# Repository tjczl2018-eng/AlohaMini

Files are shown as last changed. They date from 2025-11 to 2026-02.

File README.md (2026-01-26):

# AlohaMini
 

AlohaMini is a dual-arm mobile robot with a motorized vertical lift — beautifully designed, fully 3D-printable, and affordable.  

Built for embodied AI research and real-world manipulation. Assemble at home in ~60 minutes, customize every part, and train or deploy with LeRobot.

Note:
Use ROS only if you need URDF visualization, RViz inspection, or Gazebo simulation.

## Updates

- [2025-12-18] — URDF and simulation assets are now available for visualization and simulation (`simulation/src/Aloha/`)
- [2025-11-27] STEP (CAD) files are now available (`/hardware/mobile_base/step/`)

### What Makes It Different

- **Motorized vertical lift** — 0–60 cm travel (floor-to-table reach)
- **5-camera perception system** — top, front, back, and dual arm cameras engineered for embodied-AI reproducibility
- **Completely open-source** — hardware and software freely available
- **LeRobot-compatible** — works out of the box
- **Clean, modern design** — built for both function and aesthetics
- **Low-cost & accessible** — engineered so anyone can build a capable robot at home

## 📸 Gallery

<p align="center">
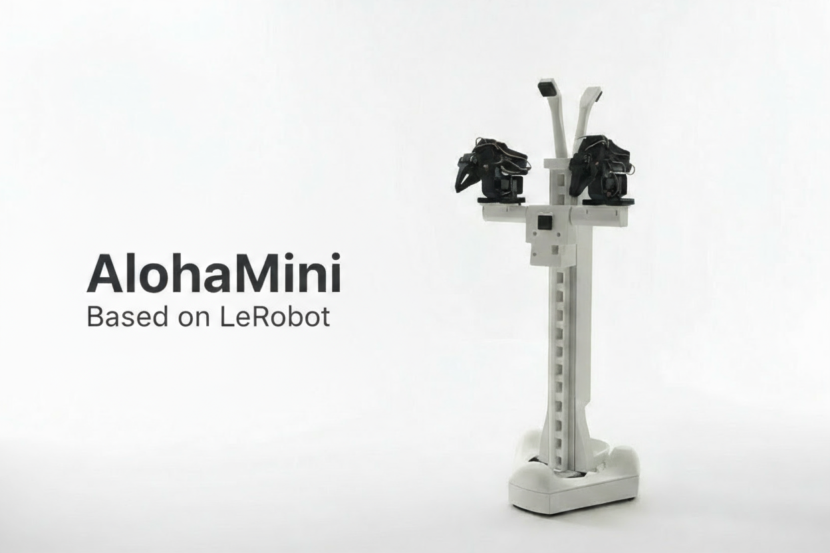
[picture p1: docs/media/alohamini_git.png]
  
</p>

## ⚙️ Bill of Materials (BOM)
### Main Components

| Component | Model / Notes | Qty | Unit Price (USD) |
|---|---|-----|---|
| Servo motors | Feetech STS3215 (12V bus) | 16 | $13.89 |
| Motor control boards | Waveshare Bus Servo Adapter (A) | 2 | $10.55 |
| Compute platform | Raspberry Pi 5 (4/8GB) | 1 | $80 |
| Cameras | 720p USB cameras (2 for arms, 3 for mobile base) | 5 | $20 |
| Mobility system | Omni wheels | 3 | $36.00 |
| Battery | 12V Li-ion pack | 2 | $32.99 |
| Frame | 3D-printed body (ABS / PETG / PLA) | — | ~4kg filament (self-print) |
| **Total** | — | — | **~$600 (self-print)** |

Note: 
- Printable STL files under `/hardware/`
- Compute platform can be replaced with Jetson Nano or similar SBCs if desired.
- URDF files will be released soon

## Quick Start

Start building and running AlohaMini:

1. **Hardware acquisition** — Purchase components and 3D print parts  
   See **[BOM & 3D-Print](docs/BOM.md)**

1. **Assembly** — build the robot in ~60 minutes (SO-ARM pre-assembled)  
   See **[assembly guide](docs/hardware_assembly.md)**

1. **Software setup & teleoperation** — install, connect, and control the robot  
   See **[software guide](software)**

##  Product Line
| Model | Build | Rigidity | Target Users |
|---|---|---|---|
| **AlohaMini** | Fully 3D-printed | Standard | Education, makers, research labs, home builds |
| **AlohaMini Pro** | Hybrid **3D-print + metal** | **3×–5× stiffer** | Algorithm-focused researchers who need plug-and-play, reliable, and stable hardware — without assembly effort |

> Same URDF & control stack across both versions — only structural materials differ.

### AlohaMini Pro Access  
Pro hardware & kits available for advanced users.  
📩 **Contact to request early access.**

## Contact
Email: liyiteng+github@gmail.com  
WeChat: liyiteng  
Videos & tutorials soon on: Bilibili / YouTube / TikTok

## Team
AlohaMini is created by:  
**Li Yiteng** / **Wu Zhiyong**

##  Acknowledgements
Thanks to the open robotics community:  
**ALOHA · LeKiwi · SO-ARM100 · SO-ARM100-Track-Axis · Pi-0.5 · LeRobot · Hugging Face**

## ⭐ Support AlohaMini
If you like this project:
- ⭐ Star the repo  
- 🔔 Follow updates  
- 💬 Join the community

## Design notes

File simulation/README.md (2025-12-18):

# AlohaMini-Simulation

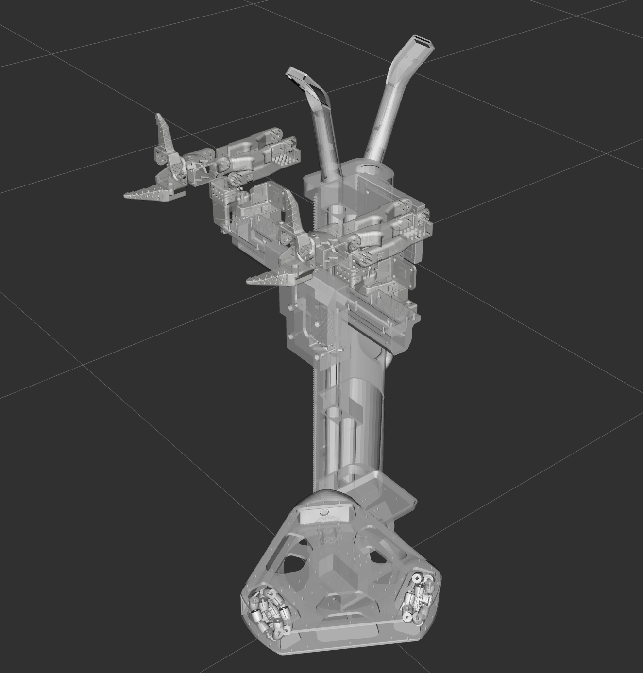
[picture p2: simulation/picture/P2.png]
AlohaMini preview


AlohaMini-Simulation bases on AlohaMini, which link is https://github.com/liyiteng/AlohaMini.

It visualizes the AlohaMini robot using RViz in both ROS 1 and ROS 2, and includes optional Gazebo integration for simulation.

This document provides separate, explicit instructions for ROS 2 and ROS 1: each section contains build (compile) and run (launch) steps targeted at typical Linux (Ubuntu) environments.

## Repository

```bash
git clone https://github.com/lemon198/AlohaMini-Simulation.git
cd AlohaMini-Simulation
```

## ROS 2 — Build & Run (colcon)

These instructions target ROS 2 (colcon-based workspaces). Adjust the distro names (Foxy/Galactic/Humble/Jazzy) as needed.

1) Install prerequisites (example):

```bash
# install colcon and ros dependencies (example for Ubuntu)
sudo apt update
sudo apt install -y python3-colcon-common-extensions python3-rosdep
```

2) Build the workspace:

```bash
colcon build   # run from repository root
```

3) Source the overlay before running:

```bash
source install/setup.bash
```

4) (Optional) Force FastDDS as the RMW implementation:

```bash
export RMW_IMPLEMENTATION=rmw_fastrtps_cpp
```

5) Run RViz2 visualization (example):

```bash
ros2 launch Aloha display.launch.py  # RViz2 visualization
```

Notes for ROS 2:
- Ensure you installed ROS 2 for your target distro and that `source /opt/ros/<distro>/setup.bash` is present in your shell if needed.
- If using mixed ROS1/ROS2 setups, configure the ROS1-ROS2 bridge separately.

## ROS 1 — Build & Run (catkin)

These instructions target ROS 1 (catkin-based workspaces) such as Melodic or Noetic.

1) Create a catkin workspace and place the repository in `src`:

```bash
mkdir -p ~/catkin_ws/src
cd ~/catkin_ws/src
git clone https://github.com/lemon198/AlohaMini-Simulation.git
cd ~/catkin_ws
```

2) Install and resolve dependencies with `rosdep`:

```bash
sudo apt update
sudo apt install -y python3-rosdep
sudo rosdep init   # only if rosdep isn't initialized yet
rosdep update
rosdep install --from-paths src --ignore-src -r -y
```

3) Build with `catkin_make`:

```bash
catkin_make
source devel/setup.bash
```

Or build with `catkin_tools` (`catkin build`):

```bash
sudo apt install -y python3-catkin-tools
cd ~/catkin_ws
catkin build
source devel/setup.bash
```

4) Run ROS 1 launch files:

```bash
roslaunch Aloha display.launch       # RViz visualization
roslaunch Aloha gazebo.launch        # Gazebo visualization
```

Notes for ROS 1:
- These commands are intended for Linux (Ubuntu). For Windows, use WSL or a Linux VM for better ROS1 support.
- If you see missing packages, double-check that package names and dependencies match your ROS distro (Melodic vs Noetic).

## Troubleshooting

- If RViz/RViz2 does not show robot models, ensure `robot_state_publisher` is running and `/tf` topics are being published.
- For mixed ROS1/ROS2 systems, verify your ROS1-ROS2 bridge configuration and topic remapping.
- If launches fail due to missing dependencies, run `rosdep install --from-paths src --ignore-src -r -y` in the workspace root.

## Contributing

Contributions are welcome. Please open issues or PRs against the upstream repository and follow its contribution guidelines.

E-mail address：s-wyw25@bjzgca.edu.cn

## Acknowledgements
Thanks to the open robotics community:

AlohaMini · ALOHA · SO-ARM101 · LeRobot 

## Future

I'll keep exploring VLA algorithms on AlohaMini and will continuously updates. Your stars are what keep this project moving forward.

## License

See the `LICENSE` file in the repository for license details.

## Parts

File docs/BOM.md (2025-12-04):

# Bill of Materials

AlohaMini follows the same architecture and terminology as LeKiwi, consisting of a Client side and a Host side.

- The Client handles computation and control.
- The Host executes commands and returns observations.

This is also commonly referred to as PC side vs. Remote side, and both naming conventions are equivalent.

AlohaMini’s Client hardware includes the mobile base and two follower arms. The arms directly reuse the SO-ARM100 design. Therefore, if you already have two SO-ARM100 arms, you only need to assemble the mobile base. Communication between the mobile base, arms, and Raspberry Pi 5 uses the same bus-servo communication system, and the build guide will explain the wiring in detail.

On AlohaMini, the Host side consists of a PC workstation and leader arms. VR controllers or other devices can also replace the leader arms, and we will release compatible controller kits soon. For beginners, we recommend starting with leader-arm teleoperation.

*Note: Table clamp, screwdriver set, soldering iron, and other common tools can be sourced as needed and are not listed in the tables below.*

## Mobile base 

| Item | Model / Notes | Qty | Unit Cost (US) | Buy (US) | Unit Cost (CN) | Buy (CN) |
|---|---|-----|---|---|---|---|
| Servo motor | Feetech / 12V 1/345 Gear(STS3215-C018)| 4 | $13.89 | [Alibaba](https://www.alibaba.com/product-detail/Feetech-STS3215-SO-ARM100-Servo-12V_1601292634404.html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) | ¥110 | [taobao](https://item.taobao.com/item.htm?id=996544351583&spm=a213gs.v2success.0.0.73c04831naDrHP) |
| Omni wheel | 4″ (≈100 mm) | 3 | $47 | [Amazon](https://www.amazon.com/Replacement-Plastic-Directional-Accessories-Platform/dp/B0F9W6QX5M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) | ¥135 | [pinduoduo](https://mobile.yangkeduo.com/goods.html?ps=kKWPC7xuzw) |
| USB camera | 720p focal length 2.4 mm, 36×36 mm form factor | 3 | — | Amazon | ¥125 | [taobao](https://item.taobao.com/item.htm?id=666278411821) |
| (optional) Bearing | 12×18×4 mm (ID × OD × W) — wheel axle bearing | 3 | — | Amazon | ¥6 | [tmall](https://detail.tmall.com/item.htm?id=824704356695) |
| Bearing | 4×13×5 mm (ID × OD × W) — lift axis bearing | 8 | — | Amazon | ¥3 | [taobao](https://item.taobao.com/item.htm?id=565418362178) |
| M2×12 Phillips screw | For camera mounts (OB_T_Camera_Mount.stl, OB_Top_Camera_Mount) | 12 | — | — | — | — |
| M3×12 hex socket screw | Total 36 pcs (Servo Mount×24 ,Side Panel×12 ) | 36 | — | — | — | — |
| M3×18 hex socket screw | For OB_Chassis_Wheel_Axle_Connector.stl | 12 | — | — | — | — |
| M3×30 hex socket screw | For OB_T_Connector_Right/Left.stl | 8 | — | — | — | — |
| M3 hex nut | For OB_T_Connector_Right/Left.stl | 8 | — | — | — | — |
| M3x5x4 heat-set insert | Total 36 pcs (Servo Mount×24, Side Panel×12) | 36 | — | Amazon | ¥5 | [taobao](https://item.taobao.com/item.htm?id=809241671998) |
| M4×12 hex socket screw | Total 20 pcs (Bearing Cover×12, Z-axis Servo Mount×8) | 20 | — | Amazon | — | — |
| M4x6x5 heat-set insert | For OB_Chassis_Bearing_Cover.stl | 12 | — | Amazon | ¥4 | [taobao](https://item.taobao.com/item.htm?id=809241671998) |
| Adhesive | Epoxy (strongly recommended) / double-sided tape — cable retention & structural bonding | 1 | — | Amazon | ¥12 | [jd](https://item.jd.com/100141557259.html) |
| Servo extension cable | SCS 3-pin, 90 cm | 2 | — | [Alibaba](https://www.alibaba.com/product-detail/3P-5264-Interface-Bus-Actuator-Connection_1601635790774.html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) | ¥3 | [taobao](https://item.taobao.com/item.htm?id=616460581906) |
| Battery | 12 V Li-ion pack with 5521 barrel jack (male & female); one pack for the Raspberry Pi 5, the other for the mobile base and follower arms.| 2 | $43 | [Amazon](https://www.amazon.com/KBT-Rechargeable-Connector-Replacement-Security/dp/B0C242DYT1/ref=sr_1_2_sspa?th=1) | ¥130 | [taobao](https://item.taobao.com/item.htm?id=890828103056) |
| USB Type-C cable | Only for testing the mobile base | 1 | $10 | [Amazon](https://www.amazon.com/Charging-etguuds-Charger-Braided-Compatible/dp/B0B8NWLLW2/?th=1) | ¥20 | [tmall](https://detail.tmall.com/item.htm?id=754024805047) |
| Waveshare Bus Servo Controller | Only for testing the mobile base | 1 | $13 | [Amazon](https://www.amazon.com/Waveshare-Integrates-Control-Circuit-Supports/dp/B0CTMM4LWK/) | ¥27 | [tmall](https://detail.tmall.com/item.htm?id=738817173460) |
| 3D-printed parts | PLA/PETG/ABS (files in /hardware/mobile_base/stl) | ~4 kg filament | — | — | — | — |

**3D Printing Parts List:**
- OB_Chassis_Bearing_Cover x3
- OB_Chassis_Servo_Mount x3
- OB_Chassis_Side_Panel x3
- OB_Chassis_Wheel_Axle_Connector x3
- OB_Chassis_Wheel_Guard x3
- OB_Top_Camera_Back_Cover x2
- OB_Chassis_Shaft_Sleeve_12_24 x3
- O_Chassis_Dowel_Pin_12_37 x3
- All other files x1

### What the Base Can Do

With only the components above, you can assemble the **mobile base** and control:

- movement  
- vertical lift  

Use the following commands to control the base:
```bash
python examples/debug/wheels.py \
   --port /dev/ttyACM0

python examples/debug/axis.py \
   --port /dev/ttyACM0
```

Use W/S/A/D to drive the base, and U/J to raise or lower the lift — all directly from your PC, without installing any single-board computer on the robot.

More details will be provided in the software setup section.

Effect after assembly:

Assembled AlohaMini mobile base
### Standalone Mode (Optional)

If you prefer the base to operate as an **independent host system** (Wi‑Fi, untethered), add:

| Item | Model / Notes | Qty | Unit Cost (US) | Buy (US) | Unit Cost (CN) | Buy (CN) |
|---|---|-----|---|---|---|---|
| Compute board | Raspberry Pi 5 (4GB/8GB) | 1 | — | [Adafruit](https://www.adafruit.com/product/5812) | ¥600 | [taobao](https://item.taobao.com/item.htm?id=688878446695) |
| DC converter | 12V → 5V / 5A buck converter | 1 | $13 | [Amazon](https://www.amazon.com/Klnuoxj-Converter-Interface-Waterproof-Compatible/dp/B0CRVW7N2J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) | ¥75 | [taobao](https://item.taobao.com/item.htm?id=800698078303) |
| Monitor | 7-inch HD IPS HDMI interface + touch + Type C power supply | 1 | — | Amazon | ¥291 | [taobao](https://item.taobao.com/item.htm?id=592070943040) |

## Follower Arms
| Item | Model / Notes | Qty | Unit Cost (US) | Buy (US) | Unit Cost (CN) | Buy (CN) |
|---|---|-----|---|---|---|---|
| Servo motor | Feetech / 12V 1/345 Gear(STS3215-C018) | 12 | $13.89 | [Alibaba](https://www.alibaba.com/product-detail/Feetech-STS3215-SO-ARM100-Servo-12V_1601292634404.html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) | ¥110 | [taobao](https://item.taobao.com/item.htm?id=996544351583&spm=a213gs.v2success.0.0.73c04831naDrHP) |
| Waveshare Bus Servo Controller | For connecting to the Raspberry Pi 5 | 2 | $13 | [Amazon](amazon.com/Waveshare-Integrates-Control-Circuit-Supports/dp/B0CTMM4LWK/) | ¥27 | [tmall](https://detail.tmall.com/item.htm?id=738817173460) |
| USB camera | 720p focal length 3.8 mm, 32×32 mm form factor | 2 | — | Amazon | ¥103 | [taobao](https://item.taobao.com/item.htm?id=590682120464) |
| 1-to-2 DC splitter cable | 30 cm, 5521 connector — for powering the arms | 1 | — | Amazon | ¥5 | [taobao](https://item.taobao.com/item.htm?id=594921965049) |
| DC extension cable | 1.5 m, 5521 connector — for powering the arms | 2 | — | Amazon | ¥2.50 | [taobao](https://item.taobao.com/item.htm?id=43628177900) |
| USB Type-C cable | For connecting to the Raspberry Pi 5 | 2 | $10 | [Amazon](https://www.amazon.com/Charging-etguuds-Charger-Braided-Compatible/dp/B0B8NWLLW2/?th=1) | ¥20 | [tmall](https://detail.tmall.com/item.htm?id=754024805047) |
| 3D-printed parts | PLA/PETG/ABS (files in /hardware/arms/stl) | 1 set | — | — | — | — |

**3D Printing Parts List:**
- All "D_*.stl" files: x2
- All "F_*.stl" files: x2

For detailed printing instructions, refer to the [SO-ARM100 project README](https://github.com/TheRobotStudio/SO-ARM100)

## Leader Arms
> **Note:** The official SO-ARM100 design uses three different gear ratios (1/147, 1/191, 1/345) for optimal performance. However, our testing shows that using a single gear ratio (1/147) provides excellent user experience and significantly simplifies assembly. The BOM below reflects this simplified configuration.

| Item | Model / Notes | Qty | Unit Cost (US) | Buy (US) | Unit Cost (CN) | Buy (CN) |
|---|---|-----|---|---|---|---|
| Servo motor | Feetech / 7.4V 1/147 Gear(STS3215-C046) | 12 | $13.89 | [Alibaba](https://www.alibaba.com/product-detail/Feetech-STS3215-SO-ARM101-Servo-7_1601430760797.html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) | ¥99 | [taobao](https://item.taobao.com/item.htm?id=996544351583&spm=a213gs.v2success.0.0.73c04831naDrHP) |
| Waveshare Bus Servo Controller | For connecting to the PC | 2 | $13 | [Amazon](https://www.amazon.com/Waveshare-Integrates-Control-Circuit-Supports/dp/B0CTMM4LWK/) | ¥27 | [tmall](https://detail.tmall.com/item.htm?id=738817173460) |
| Battery | 5V Li-ion pack (5600mAh) | 1 | — | Amazon | ¥30 | [taobao](https://item.taobao.com/item.htm?id=765749120668) |
| 1-to-2 DC splitter cable | 70 cm — for powering the arms | 1 | — | Amazon | ¥5 | [taobao](https://item.taobao.com/item.htm?id=594921965049) |
| USB Type-C cable | For connecting to the PC | 2 | $10 | [Amazon](https://www.amazon.com/Charging-etguuds-Charger-Braided-Compatible/dp/B0B8NWLLW2/?th=1) | ¥20 | [tmall](https://detail.tmall.com/item.htm?id=754024805047) |
| 3D-printed parts | PLA/PETG/ABS (files in /hardware/arms/stl) | 1 set | — | — | — | — |

**3D Printing Parts List:**
- All "D_*.stl" files: x2
- All "L_*.stl" files: x2

For detailed printing instructions, refer to the [SO-ARM100 project README](https://github.com/TheRobotStudio/SO-ARM100)

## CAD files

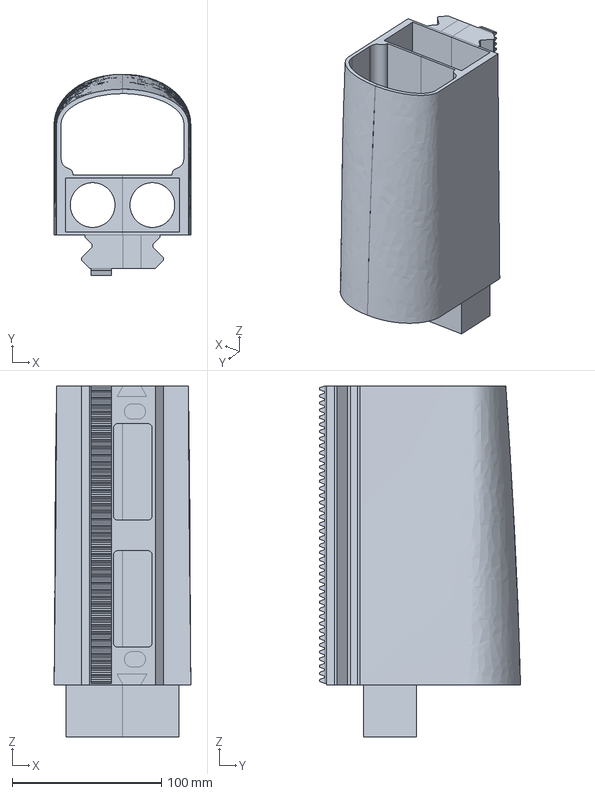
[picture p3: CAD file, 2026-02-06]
hardware/mobile_base/step/O_Main_Assembly_Post3.stp
91.5 x 134.6 x 235.0 mm

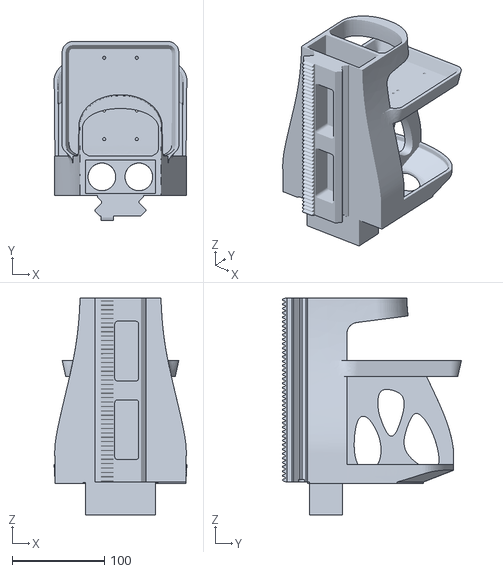
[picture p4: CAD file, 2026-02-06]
hardware/mobile_base/stl/O_Main_Assembly_Post4.stl
143.8 x 193.8 x 235.0

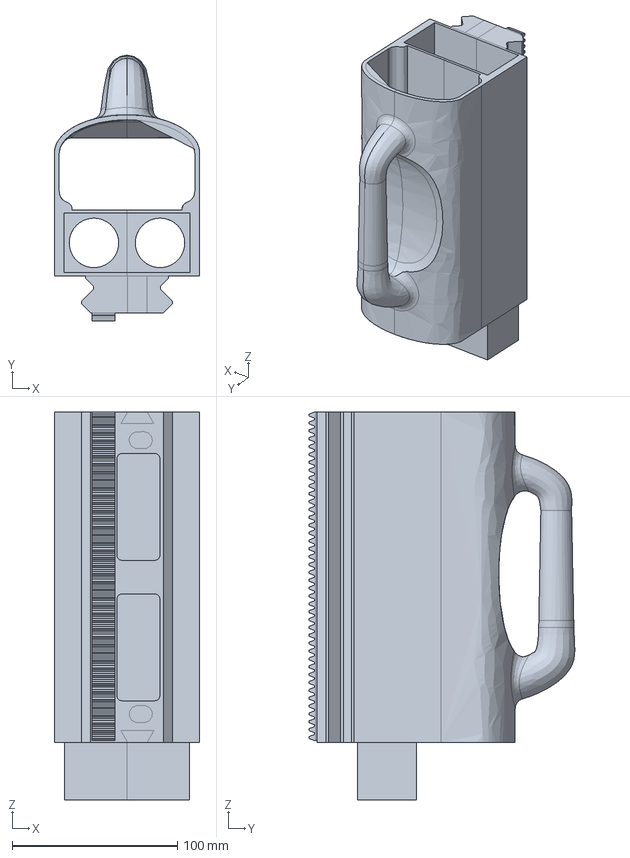
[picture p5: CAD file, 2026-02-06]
hardware/mobile_base/step/O_Main_Assembly_Post2.stp
88.1 x 160.9 x 235.0 mm

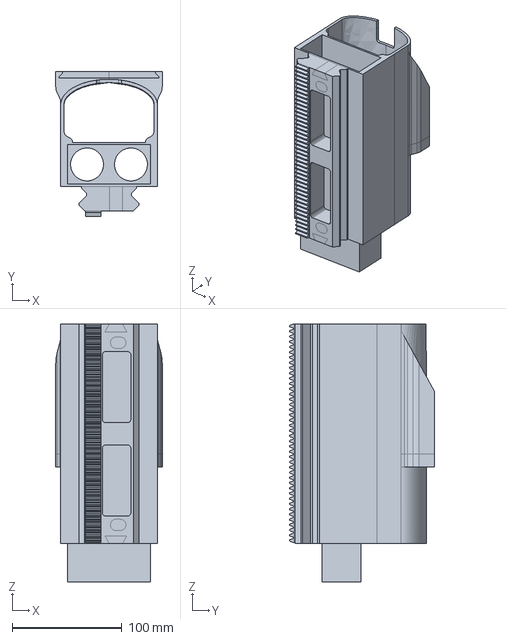
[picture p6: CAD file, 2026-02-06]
hardware/mobile_base/step/O_Main_Assembly_Post1.stp
97.0 x 131.7 x 235.0 mm

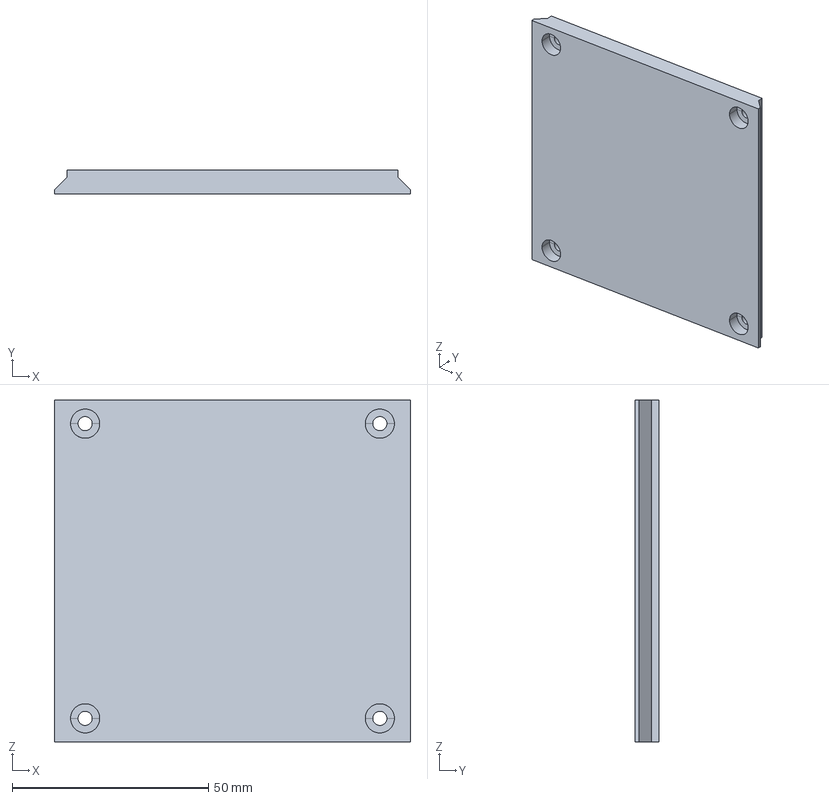
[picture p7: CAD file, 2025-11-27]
hardware/mobile_base/stp/OB_Main_Monitor_Connector.stp
90.6 x 6.00 x 87.0 mm

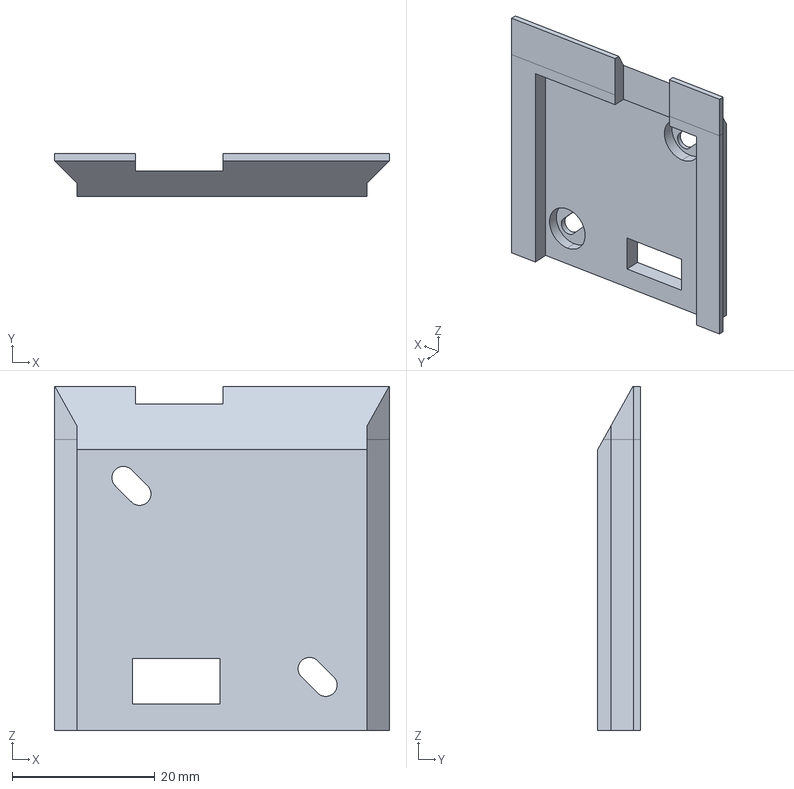
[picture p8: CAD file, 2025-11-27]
hardware/mobile_base/stp/OB_T_Camera_Mount.stp
46.9 x 6.00 x 48.2 mm

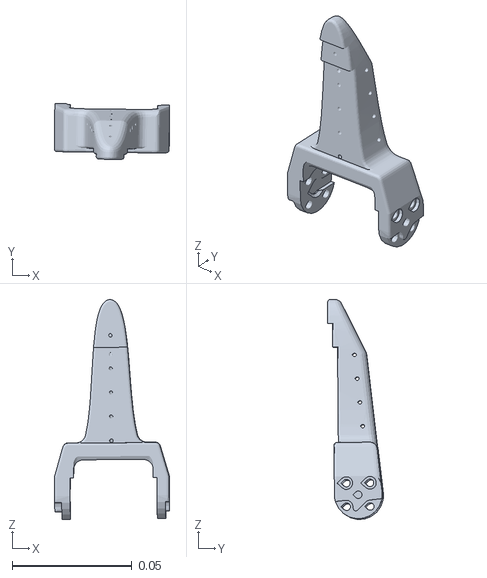
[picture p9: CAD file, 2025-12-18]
simulation/src/Aloha/meshes/left_link6.STL
0.0483 x 0.0233 x 0.092

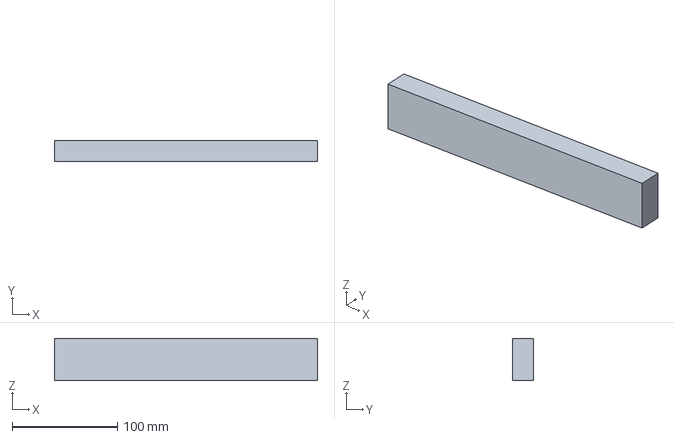
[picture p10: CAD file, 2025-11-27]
hardware/mobile_base/stp/O_T_Connector_Cross_Bar.stp
250.0 x 20.0 x 40.0 mm

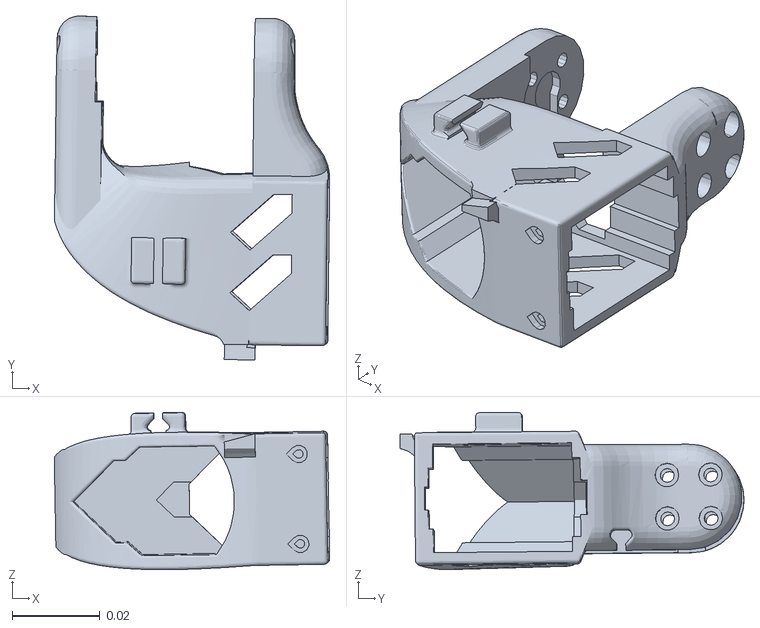
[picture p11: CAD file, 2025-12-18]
simulation/src/Aloha/meshes/right_link4.STL
0.0628 x 0.0785 x 0.0359

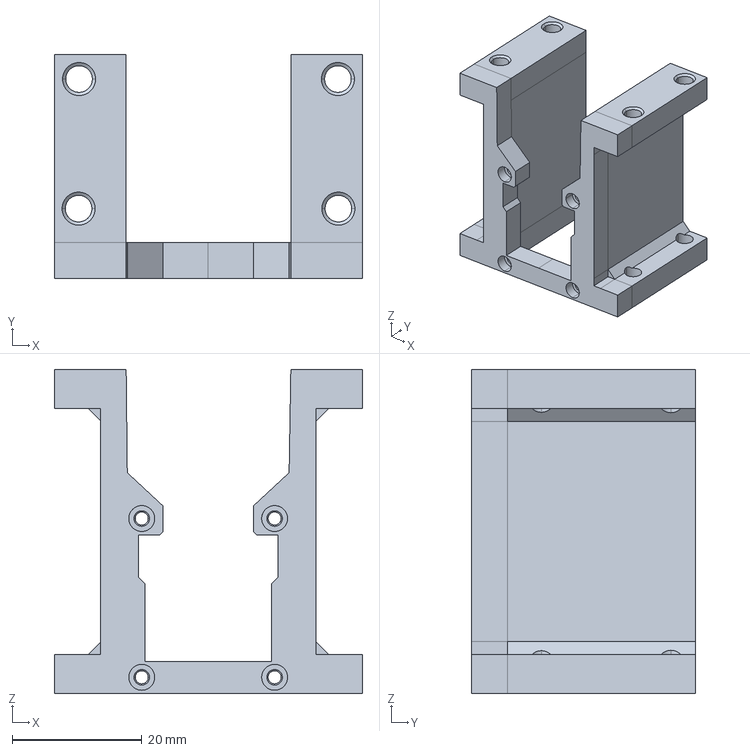
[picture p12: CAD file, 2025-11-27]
hardware/mobile_base/stp/OB_Chassis_Servo_Mount.stp
47.6 x 34.5 x 50.0 mm

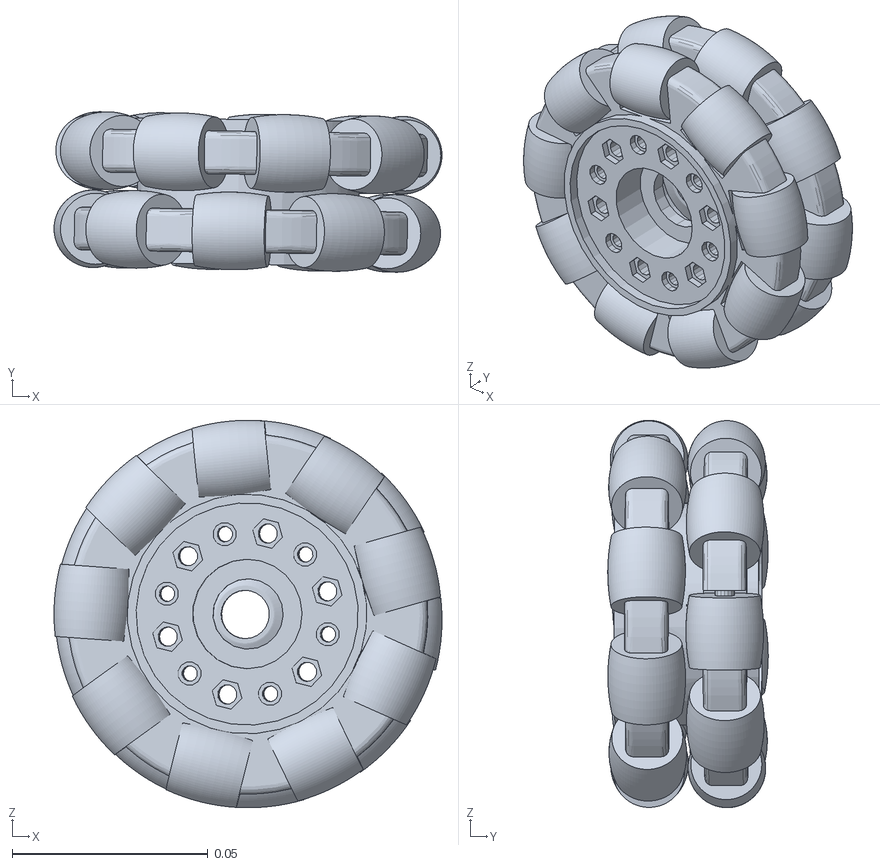
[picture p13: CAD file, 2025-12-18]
simulation/src/Aloha/meshes/wheel3.STL
0.0991 x 0.041 x 0.099

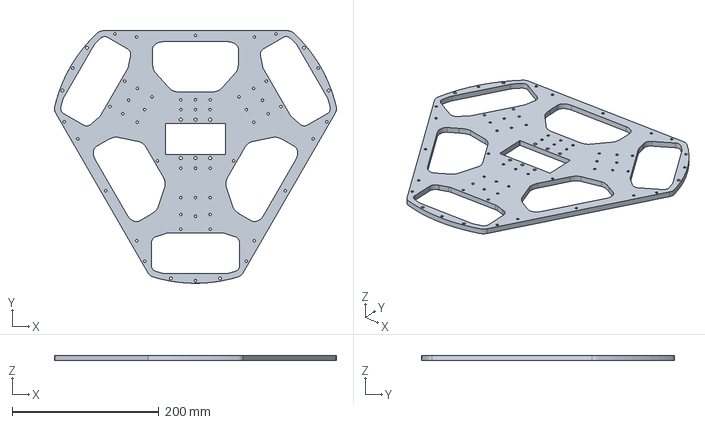
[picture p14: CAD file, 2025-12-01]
hardware/mobile_base/step/O_Chassis_Lower_Plate.stp
384.5 x 344.3 x 7.00 mm

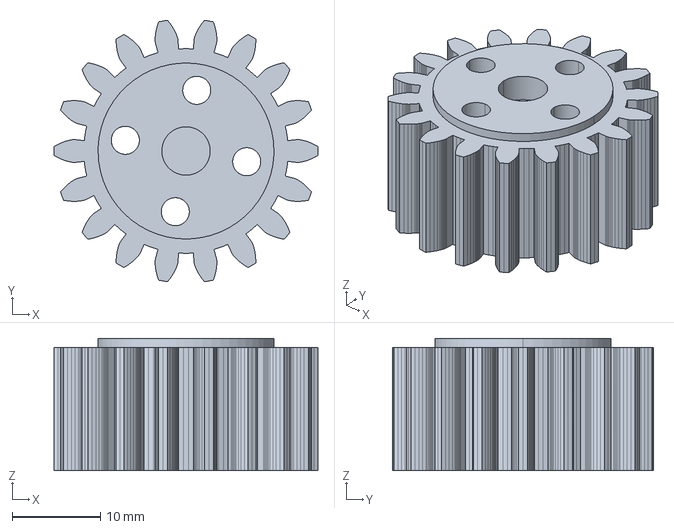
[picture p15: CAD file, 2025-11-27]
hardware/mobile_base/stp/OB_Z_Axis_Servo_Gear.stp
30.0 x 29.7 x 15.0 mm

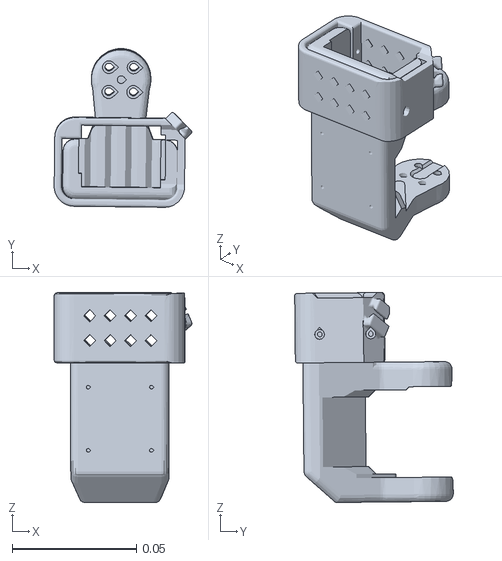
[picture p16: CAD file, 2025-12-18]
simulation/src/Aloha/meshes/right_link1.STL
0.0553 x 0.0638 x 0.0844

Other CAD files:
hardware/mobile_base/stp/OB_Z_Axis_Servo_Mount.stp
simulation/src/Aloha/meshes/left_base.STL
hardware/mobile_base/stp/O_Chassis_Upper_Plate.stp
hardware/mobile_base/stl/OB_Chassis_Bearing_Cover.stl
hardware/mobile_base/stl/OB_Chassis_Servo_Mount.stl
hardware/mobile_base/stl/OB_Chassis_Shaft_Sleeve_12_24.stl
hardware/mobile_base/stl/OB_Chassis_Side_Panel.stl
hardware/mobile_base/stl/OB_Chassis_Wheel_Axle_Connector.stl
hardware/mobile_base/stl/OB_Main_Monitor_Connector.stl
hardware/mobile_base/stl/OB_T_Camera_Mount.stl
hardware/mobile_base/stl/OB_T_Connector_Left.stl
hardware/mobile_base/stl/OB_T_Connector_Middle.stl
hardware/mobile_base/stl/OB_T_Connector_Right.stl
hardware/mobile_base/stl/OB_Top_Camera_Back_Cover.stl
hardware/mobile_base/stl/OB_Z_Axis_Bracket.stl
hardware/mobile_base/stl/OB_Z_Axis_Servo_Gear.stl
hardware/mobile_base/stl/OB_Z_Axis_Servo_Mount.stl
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

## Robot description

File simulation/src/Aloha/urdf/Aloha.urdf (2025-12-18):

<?xml version="1.0" encoding="utf-8"?>
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
<robot name="Aloha">
  <link name="base_link">
    <inertial>
      <origin xyz="-0.00084647910851246 0.00978916757496985 0.344753325406094" rpy="0 0 0" />
      <mass value="5.09802085015176" />
      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
    </inertial>
    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
  </link>
  <link name="wheel1">
    <inertial>
      <origin xyz="-5.2748796340582E-05 0.0157741139634841 -1.84430449176598E-07" rpy="0 0 0" />
      <mass value="0.19481896281763" />
      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
    </inertial>
    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
  </link>
  <joint name="wheel1" type="continuous">
    <origin xyz="-0.1538 0.091161 0.0422" rpy="0 0 -2.1099" />
    <parent link="base_link" />
    <child link="wheel1" />
    <axis xyz="0 -1 0" />
  </joint>
  <link name="wheel2">
    <inertial>
      <origin xyz="-6.44947300230958E-06 0.0157740656100239 -5.23561600380557E-05" rpy="0 0 0" />
      <mass value="0.194818035649416" />
      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
    </inertial>
    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
  </link>
  <joint name="wheel2" type="continuous">
    <origin xyz="0.15563 0.087993 0.0422" rpy="0 0 2.086" />
    <parent link="base_link" />
    <child link="wheel2" />
    <axis xyz="0 -1 0" />
  </joint>
  <link name="wheel3">
    <inertial>
      <origin xyz="0.000217589099159171 0.0157726511952609 -4.56400979924609E-05" rpy="0 0 0" />
      <mass value="0.194818526867466" />
      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
    </inertial>
    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
  </link>
  <joint name="wheel3" type="continuous">
    <origin xyz="-0.0020354 -0.17875 0.0422" rpy="0 0 0" />
    <parent link="base_link" />
    <child link="wheel3" />
    <axis xyz="-0.015476 -0.99988 0" />
  </joint>
  <link name="vertical_link">
    <inertial>
      <origin xyz="-0.000281866140488002 0.00785823838067955 0.630167237552405" rpy="0 0 0" />
      <mass value="1.13349901272872" />
      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
    </inertial>
    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
  </link>
  <joint name="vertical_move" type="prismatic">
    <origin xyz="-0.001045 -0.067891 0.064" rpy="0 0 0" />
    <parent link="base_link" />
    <child link="vertical_link" />
    <axis xyz="0 1.8801E-05 1" />
    <limit lower="0" upper="0" effort="0" velocity="0" />
  </joint>
  <link name="left_base">
    <inertial>
      <origin xyz="-6.47167646904735E-05 0.0317790321031433 0.0165976346519832" rpy="0 0 0" />
      <mass value="0.198100409133884" />
      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
    </inertial>
    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
  </link>
  <joint name="left_base" type="fixed">
    <origin xyz="0.15726 0.026474 0.68821" rpy="1.5721 0 -0.01193" />
    <parent link="vertical_link" />
    <child link="left_base" />
    <axis xyz="0 0 0" />
  </joint>
  <link name="left_link1">
    <inertial>
      <origin xyz="0.000121106970690763 -0.0313187111675913 0.0119674003207884" rpy="0 0 0" />
      <mass value="0.124705001245189" />
      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
    </inertial>
    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
  </link>
  <joint name="left_joint1" type="revolute">
    <origin xyz="-9.9427E-05 0.065387 0.045495" rpy="-1.5721 0.01193 -1.5058E-05" />
    <parent link="left_base" />
    <child link="left_link1" />
    <axis xyz="0.00011908 0.0099879 -0.99995" />
    <limit lower="0" upper="0" effort="0" velocity="0" />
  </joint>
  <link name="left_link2">
    <inertial>
      <origin xyz="0.019956873522225 0.0742856296056551 0.00422113879640418" rpy="0 0 0" />
      <mass value="0.159995189384934" />
      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
    </inertial>
    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
  </link>
  <joint name="left_joint2" type="revolute">
    <origin xyz="-0.0172799395963306 -0.0311811002780606 0.0539361523404946" rpy="0 0 0" />
    <parent link="left_link1" />
    <child link="left_link2" />
    <axis xyz="0.999994864047587 -0.00320379392081127 8.70801950002401E-05" />
    <limit lower="0" upper="0" effort="0" velocity="0" />
  </joint>
  <link name="left_link3">
    <inertial>
      <origin xyz="0.0188635530589078 -0.0764818324673495 0.000740365189654368" rpy="0 0 0" />
      <mass value="0.135542971850972" />
      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
    </inertial>
    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
  </link>
  <joint name="left_joint3" type="revolute">
    <origin xyz="0.0028523 0.11238 0.028829" rpy="0 0 0" />
    <parent link="left_link2" />
    <child link="left_link3" />
    <axis xyz="0.99996 -0.0032908 0.0088132" />
    <limit lower="0" upper="0" effort="0" velocity="0" />
  </joint>
  <link name="left_link4">
    <inertial>
      <origin xyz="0.0279838202754113 -0.0363068236889853 0.000384829033235112" rpy="0 0 0" />
      <mass value="0.0742878691881685" />
      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
    </inertial>
    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
  </link>
  <joint name="left_joint4" type="revolute">
    <origin xyz="0.00048209729405399 -0.134148581563103 0.00362381075655138" rpy="0 0 0" />
    <parent link="left_link3" />
    <child link="left_link4" />
    <axis xyz="0.999774464019127 -0.0121028846500289 0.0174511110940406" />
    <limit lower="0" upper="0" effort="0" velocity="0" />
  </joint>
  <link name="left_link5">
    <inertial>
      <origin xyz="8.08393796061513E-05 -0.0263409418103688 -0.00560236977442241" rpy="0 0 0" />
      <mass value="0.0992047568868334" />
      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
    </inertial>
    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
  </link>
  <joint name="left_joint5" type="revolute">
    <origin xyz="0.0197383915384675 -0.0617903364033804 -0.000262136225517406" rpy="0 0 0" />
    <parent link="left_link4" />
    <child link="left_link5" />
    <axis xyz="0.0119284594940202 0.999878198776736 0.0100647635386641" />
    <limit lower="0" upper="0" effort="0" velocity="0" />
  </joint>
  <link name="left_link6">
    <inertial>
      <origin xyz="-0.0204038927902523 -0.00159758044103914 0.029746450173969" rpy="0 0 0" />
      <mass value="0.0208454114831758" />
      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
    </inertial>
    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
  </link>
  <joint name="left_joint6" type="revolute">
    <origin xyz="0.0187720220742788 -0.0238281541937461 0.0200035092438084" rpy="0 0 0" />
    <parent link="left_link5" />
    <child link="left_link6" />
    <axis xyz="-0.999889727846743 0.0120164296808642 -0.00872568417324989" />
    <limit lower="0" upper="0" effort="0" velocity="0" />
  </joint>
  <link name="right_base">
    <inertial>
      <origin xyz="-6.47167852975139E-05 0.0317790320234692 0.0165976345779274" rpy="0 0 0" />
      <mass value="0.198100409607737" />
      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
    </inertial>
    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
  </link>
  <joint name="right_base" type="fixed">
    <origin xyz="-0.156575640990368 0.0302182544430658 0.688907726663402" rpy="1.5720584644847 0 -0.0119300103453133" />
    <parent link="vertical_link" />
    <child link="right_base" />
    <axis xyz="0 0 0" />
  </joint>
  <link name="right_link1">
    <inertial>
      <origin xyz="0.000121106969499962 -0.0313187111595207 0.011967400309894" rpy="0 0 0" />
      <mass value="0.124705001332934" />
      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
    </inertial>
    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
  </link>
  <joint name="right_joint1" type="revolute">
    <origin xyz="-9.94268621290484E-05 0.0653870978342812 0.04549462735273" rpy="-1.5720585543069 0.0119300008426609 -1.50580260816763E-05" />
    <parent link="right_base" />
    <child link="right_link1" />
    <axis xyz="0.000119075661457425 0.00998790806073686 -0.999950112512398" />
    <limit lower="0" upper="0" effort="0" velocity="0" />
  </joint>
  <link name="right_link2">
    <inertial>
      <origin xyz="0.0199568735153524 0.0742856296207353 0.00422113879547792" rpy="0 0 0" />
      <mass value="0.159995189339826" />
      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
    </inertial>
    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
  </link>
  <joint name="right_joint2" type="revolute">
    <origin xyz="-0.0172799395963307 -0.0311811002780605 0.0539361523404946" rpy="0 0 0" />
    <parent link="right_link1" />
    <child link="right_link2" />
    <axis xyz="0.999994864047587 -0.00320379392081127 8.70801950002401E-05" />
    <limit lower="0" upper="0" effort="0" velocity="0" />
  </joint>
  <link name="right_link3">
    <inertial>
      <origin xyz="0.0188635531409881 -0.0764818322790424 0.000740365178020785" rpy="0 0 0" />
      <mass value="0.135542972322652" />
      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
    </inertial>
    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
  </link>
  <joint name="right_joint3" type="revolute">
    <origin xyz="0.00285228244048635 0.112379078107107 0.0288286304493108" rpy="0 0 0" />
    <parent link="right_link2" />
    <child link="right_link3" />
    <axis xyz="0.999955748189333 -0.00329083176439995 0.0088131770326472" />
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

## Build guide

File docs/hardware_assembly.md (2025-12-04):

# Assembly

## Mobile Base Assembly

1. Using the servo software ([FD Debug Tool v1.9.8.3](https://www.feetechrc.com/Data/feetechrc/upload/file/20240622/FD1.9.8.3.zip)), assign ID numbers 8, 9, 10, and 11 to the servos respectively.

   **How to adjust:**
   
   To assign ID numbers to the servos using the FD Debug Tool:
   
   - **Download and install** the FD Debug Tool from the link above
   - **Connect** the servo to your computer using the Waveshare Bus Servo Controller (via USB) 
   - **Launch** the FD Debug Tool software
   - **Select** the correct COM port and set the baud rate (typically 1000000 or as specified in your servo manual)
   - **Click** "Scan Servo" to detect the connected servo and its current ID
   - **Change the ID** by entering the desired number (8, 9, 10, or 11) in the ID field
   - **Click** "Write" or "Save" to update the servo's ID
   - **Disconnect** the servo and repeat the process for each remaining servo
   
   **Note:** Make sure to connect and configure only one servo at a time to avoid ID conflicts during the setup process.

1. Connect servos 8, 9, and 10 using the included 20cm servo cables, and connect servos 10 and 11 using a 90cm servo cable.


3. Install M3 heat-set inserts into the servo brackets using a soldering iron.


4. Secure the servos using the small screws included with the servos.


5. Install the wheel axle connectors.

If the connector doesn't fit, sand it down for a better fit.

Connector installation complete (if it's loose, tighten with screws or use epoxy resin for bonding; no additional treatment needed if it's tight enough).


6. Mount the servos to the chassis plate.

Follow the servo order as shown in the image.


7. Secure the servos to the chassis plate using M3x14 screws.


8. Attach the omni wheels to the servo connector using M3x18 screws.



9.  (optional)Install the chassis bearings.
Insert the bearings (12x18x4) into the dowel pin and shaft sleeves.



Install the M4 heat-set inserts into the Chassis_Bearing_Cover, then fasten it using M4x12 screws.


10. Install M3 heat-set inserts into the side plates.


11. Assemble the main posts like building blocks - there are 4 in total. Use epoxy resin or double-sided tape to bond the parts together.


12. Install the lift axis. Prepare the materials according to the BOM list.


13. Secure the gear using the screws included with the servo.


14. Insert the gear into the Axis_Servo_Mount.


15. Secure the Axis_Bracket to the servo using the included M3x6 screws from the servo.


17. Install the T-bracket.


18. Secure it with epoxy resin.
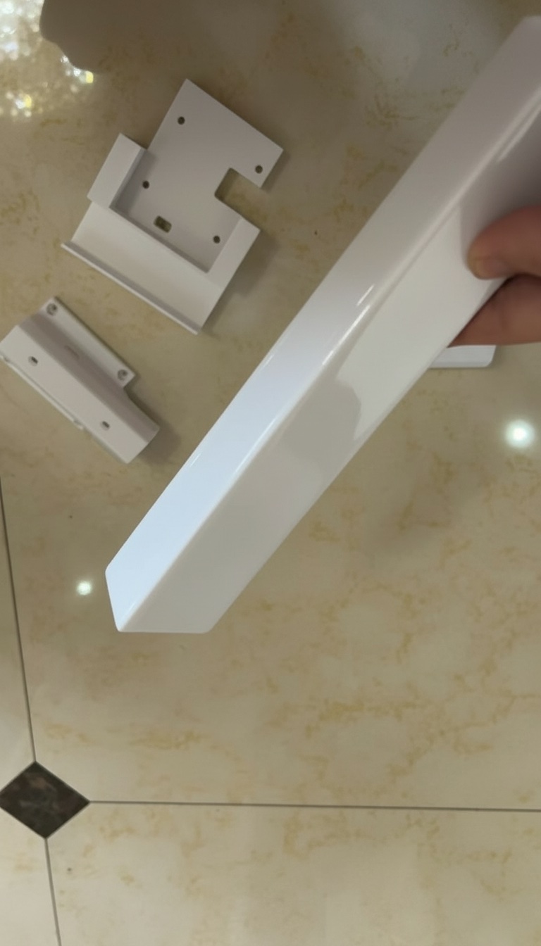
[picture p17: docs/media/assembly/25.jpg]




19. Slide the lift axis into the T-bracket.



20. Install the Top and Back cameras.
Remove the two screws from the camera back cover.


21. Reinstall the back cover using M2x12 screws, sandwiching the printed part in between.


22. Route the camera cable through the internal channel of the printed part.


23. Secure the display to the printed part using the included M3 servo screws.


24. Slide the display into the rear slot of the main post.


25. Install the Front camera using the same method as the Top camera.
Slide it into the slot. If there are any burrs on the printed part, file them down for a smooth fit.

26. Route the USB Type-C data cable and DC power cable through the hole on the rear side of the main post.


27. Mobile Base assembly complete!


## Leader arms and Follower arms
For the assembly of Leader arms and Follower arms, please refer to the tutorial: [SO-101 Assembly Guide](https://huggingface.co/docs/lerobot/so101). 

## Follower arms and Mobile Base Assembly

1. Secure the robotic arm to both sides of the T-bracket using four M3x30 hex screws and four M3 nuts.
   

2. Connect the 90cm servo cable from servo #11 to the other port on the Waveshare controller board of the **left arm**.
   

3. Attach the 12V to 5V step-down converter to the base and connect it to the Raspberry Pi.
   

4. Connect the 12V lithium battery to the step-down converter to provide power.
   

5. Connect the male plug of the 1-to-2 DC splitter cable to the female connectors of the two DC extension cables.
   

6. Connect the second 12V lithium battery to the female connector of the 1-to-2 DC splitter cable.
   

7. Assembly fully complete!


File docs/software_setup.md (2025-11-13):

# software_setup

There are two ways to run **AlohaMini** with **LeRobot**:

## **Method 1 — For existing LeRobot users**
If you’re already familiar with LeRobot, simply copy the files from  
`alohamini/software` into your existing LeRobot workspace.  
Then follow the configuration and command-line examples in the repository:  
👉 **https://github.com/liyiteng/lerobot_alohamini**

## **Method 2 — Recommended for beginners**
If you’re new to LeRobot and haven’t set it up before, it’s easier to clone the integrated repository directly:  
👉 **https://github.com/liyiteng/lerobot_alohamini**

This repository bundles **LeRobot + AlohaMini** together, so no manual copying or path configuration is required.

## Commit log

2025-11-13 add: AlohaMini mobile base assembly STL
2025-11-27 feat(cad): add STEP files
    [OB_Chassis_Bearing_Cover.stl, OB_Chassis_Bearing_Cover.stp, OB_Chassis_Servo_Mount.stl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]
2025-12-01 chore: update O_Chassis_Lower_Plate.stp hole size from M3 to M4
    [O_Chassis_Lower_Plate.stl, O_Chassis_Lower_Plate.stp]
2025-12-04 docs(bom): strongly recommend using epoxy instead of double-sided tape
2025-12-04 docs(bom):strongly recommend using epoxy instead of double-sided tape
2025-12-04 docs: update assembly
2026-02-06 feat: raise lift rack by 1mm for tighter fit
    [O_Main_Assembly_Post1.stl, O_Main_Assembly_Post1.stp, O_Main_Assembly_Post2.stl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]
